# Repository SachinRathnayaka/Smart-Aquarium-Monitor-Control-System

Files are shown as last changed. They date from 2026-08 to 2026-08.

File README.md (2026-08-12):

<div align="center">

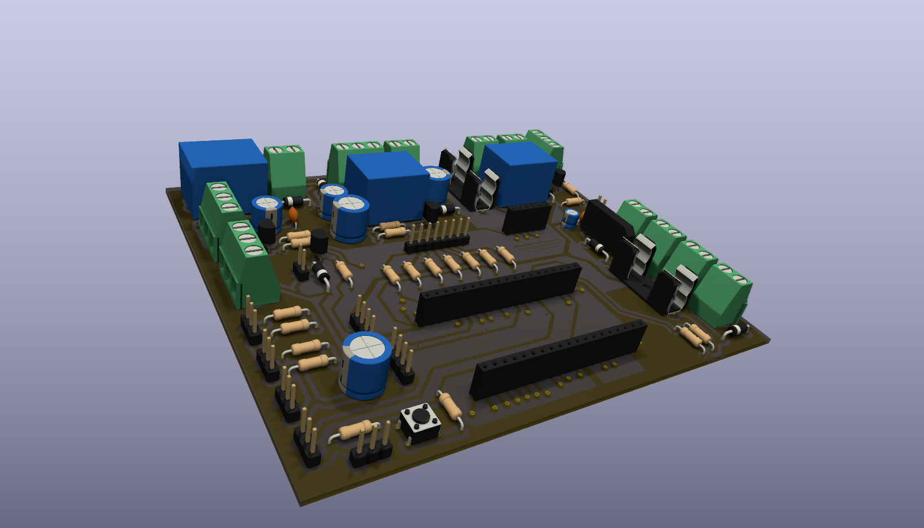
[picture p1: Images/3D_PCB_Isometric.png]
SRAqua Guard PCB


# 🐠 SRAqua Guard
### Ultimate Smart Aquarium Monitor & Automation System

*Real-time water telemetry · Intelligent automation · Voice control · Cross-platform monitoring*

---













**Author:** [Sachin Rathnayaka](https://github.com/SachinRathnayaka) &nbsp;·&nbsp; **Repo:** [Smart-Aquarium-Monitor-Control-System](https://github.com/SachinRathnayaka/Smart-Aquarium-Monitor-Control-System) &nbsp;·&nbsp; **Live Demo:** [Web Dashboard](https://sachinrathnayaka.github.io/Smart-Aquarium-Monitor-Control-System/)

</div>

---

## 📖 Table of Contents

- [Project Status](#-project-status)
- [Project Overview](#-project-overview)
- [Visual Showcase](#-visual-showcase)
- [Key Features](#-key-features)
- [System Architecture](#-system-architecture)
- [Repository Structure](#-repository-structure)
- [Getting Started](#-getting-started)
  - [Prerequisites](#prerequisites)
  - [1 · Firmware (ESP32)](#1--firmware-esp32)
  - [2 · Web Dashboard](#2--web-dashboard)
  - [3 · Android App](#3--android-app)
  - [4 · Windows Desktop App](#4--windows-desktop-app)
  - [Pre-built Binaries](#pre-built-binaries)
- [Firebase Configuration](#-firebase-configuration)
- [Voice Commands](#-voice-commands)
- [Sensor Calibration](#-sensor-calibration)
- [Troubleshooting](#-troubleshooting)
- [Electrical Safety](#-electrical-safety)
- [Hardware & PCB](#-hardware--pcb)
- [Bill of Materials](#-bill-of-materials-summary)
- [Roadmap](#️-roadmap)
- [Contributing](#-contributing)
- [Licensing](#-licensing)

---

## 🚧 Project Status

**Status: Active Development**

SRAqua Guard is an actively developed open-source hardware and software project. Features, firmware behaviour, PCB revisions, and application interfaces may change between releases. The project is functional and has been tested with real hardware — see the Visual Showcase for screenshots. Always refer to the latest `main` branch for the most current state.

| Component | Status |
|---|---|
| ESP32 Firmware | ✅ Functional |
| Web Dashboard | ✅ Functional |
| Android App | ✅ Functional |
| Windows Desktop App | ✅ Functional |
| KiCad PCB (Hardware) | ✅ Complete |
| Documentation | ✅ Complete |

---

## 🌊 Project Overview

**SRAqua Guard** is a fully open-source, advanced IoT aquarium monitoring and automation system that transforms any aquarium into an intelligently managed ecosystem. The system is built around an **ESP32 microcontroller** with a custom **KiCad PCB**, pushing real-time sensor telemetry to **Firebase Realtime Database**, and surfaced through three client platforms — a browser-based web dashboard, an Android mobile app, and a Windows desktop app.

The firmware is engineered with a **fully non-blocking `millis()` architecture**, a **DS3231 RTC** as the sole time source (ensuring offline-safe automation), and intelligent fallback behavior: the system continues sensing, controlling, and displaying locally even without Wi-Fi. When battery voltage drops below a threshold, the ESP32 enters a **5-minute deep sleep cycle** to preserve power.

> [!NOTE]
> This project includes **240 V AC mains wiring** for the water heater relay. All high-voltage sections must be handled by a qualified person. Use appropriate insulation, cable sleeving, and maintain required creepage clearances at all times.

---

## 🖼️ Visual Showcase

### Web Dashboard

| Overview | Firebase Setup | Theme Settings |
|:---:|:---:|:---:|
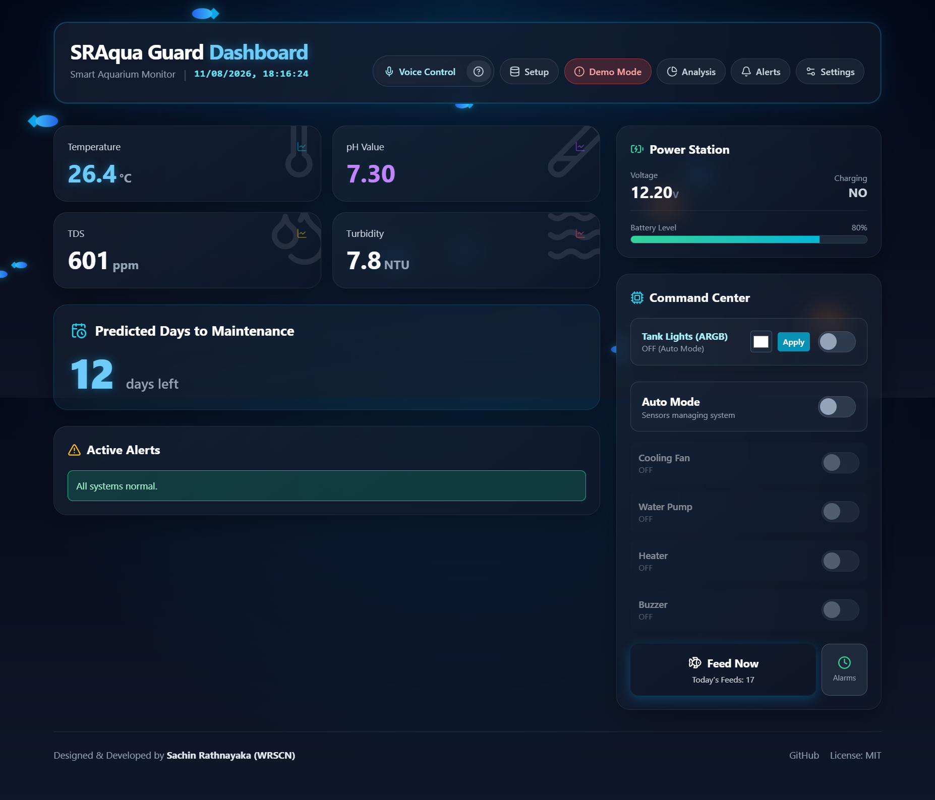
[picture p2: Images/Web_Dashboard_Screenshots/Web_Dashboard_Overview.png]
Overview
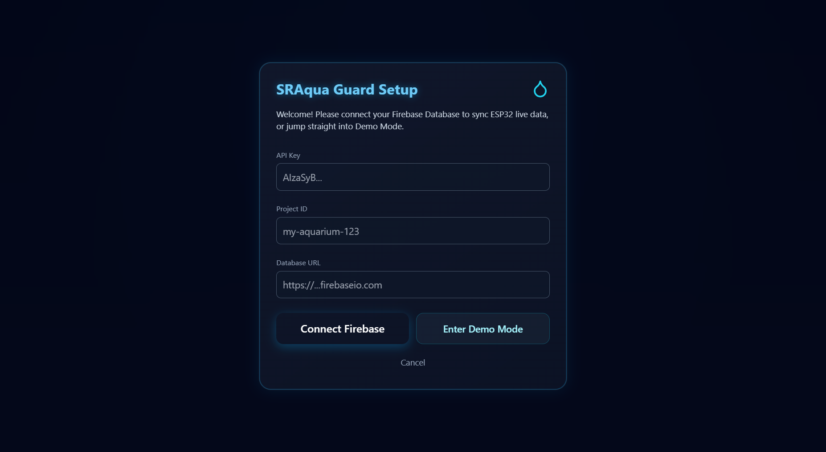
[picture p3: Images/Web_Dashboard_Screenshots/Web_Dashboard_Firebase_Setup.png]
Setup
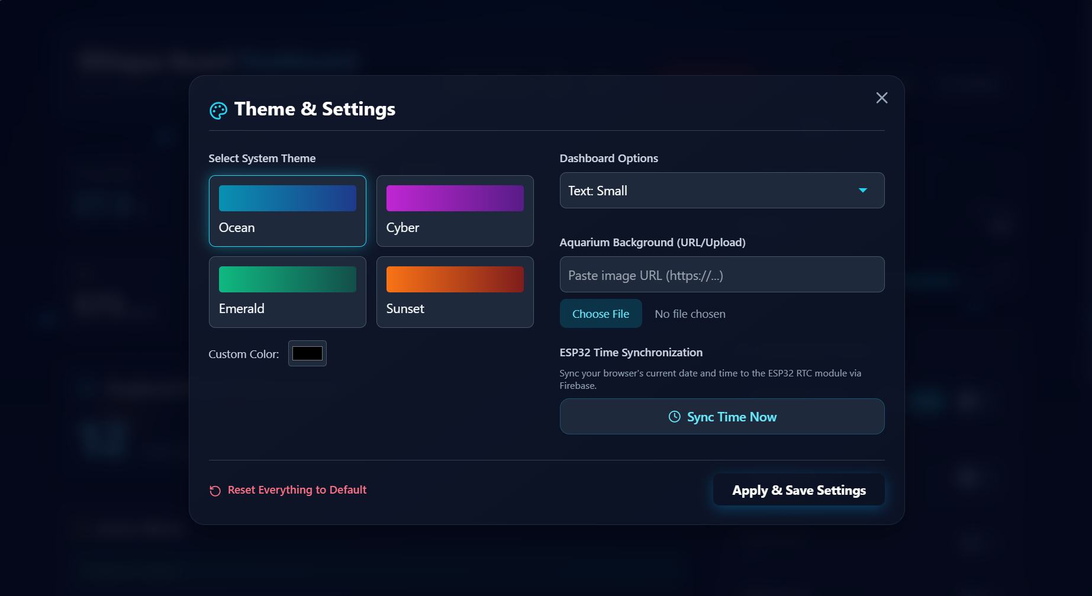
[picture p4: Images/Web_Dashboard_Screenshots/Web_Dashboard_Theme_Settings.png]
Themes
|  |  |  |

| 21-Day Sensor Analytics | 21-Day Feed Analytics | Auto Feeder Scheduler |
|:---:|:---:|:---:|
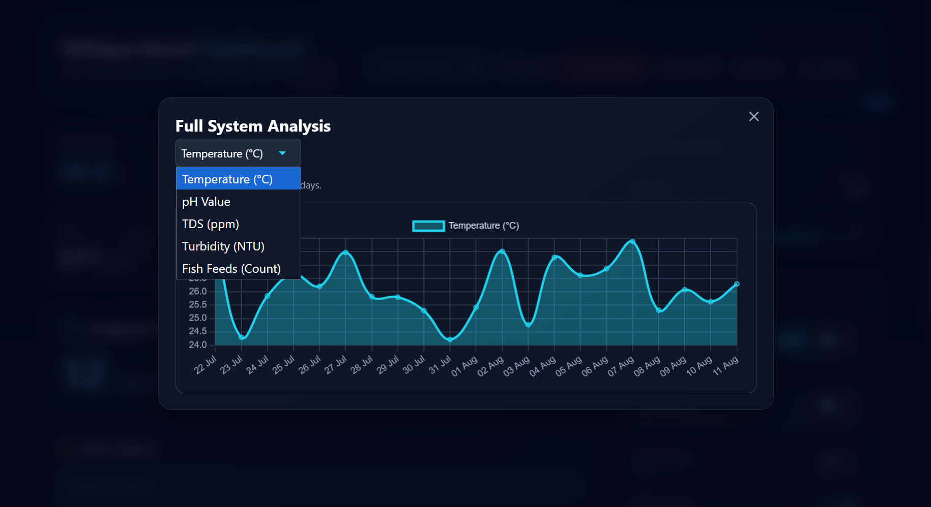
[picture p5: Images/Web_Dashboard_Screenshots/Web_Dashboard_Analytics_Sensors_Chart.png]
Sensor Chart
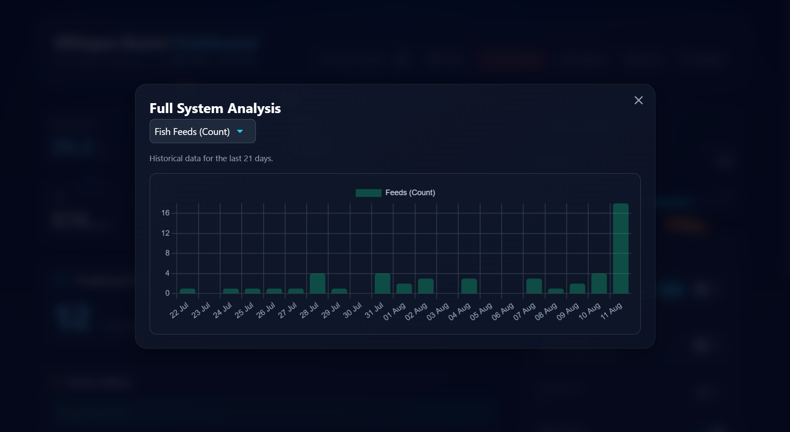
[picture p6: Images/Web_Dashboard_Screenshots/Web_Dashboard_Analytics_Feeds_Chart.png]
Feed Chart
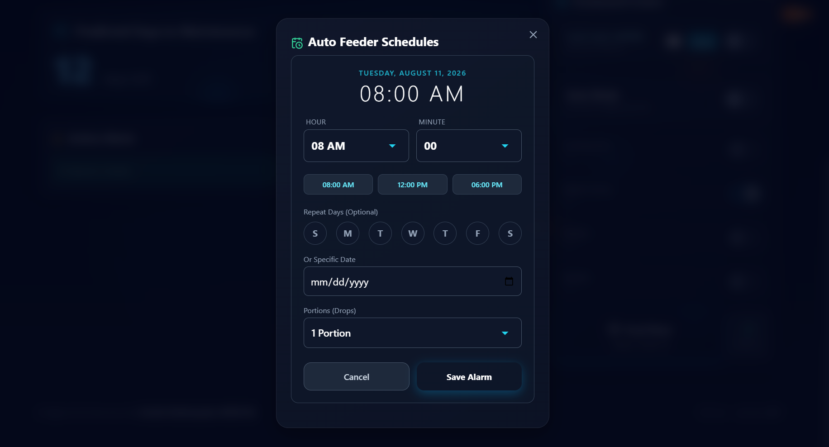
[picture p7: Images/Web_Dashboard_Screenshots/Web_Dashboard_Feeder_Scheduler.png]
Scheduler
|  |  |  |

| Live Voice Assistant | Voice Commands List | Alerts & History |
|:---:|:---:|:---:|
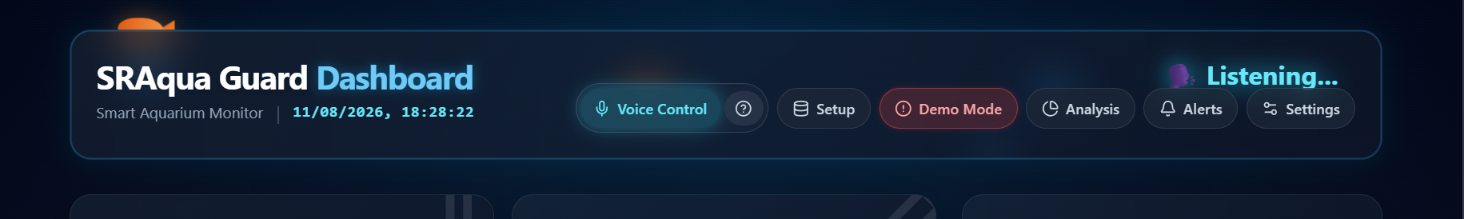
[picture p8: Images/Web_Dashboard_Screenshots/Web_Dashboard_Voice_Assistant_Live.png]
Voice Live
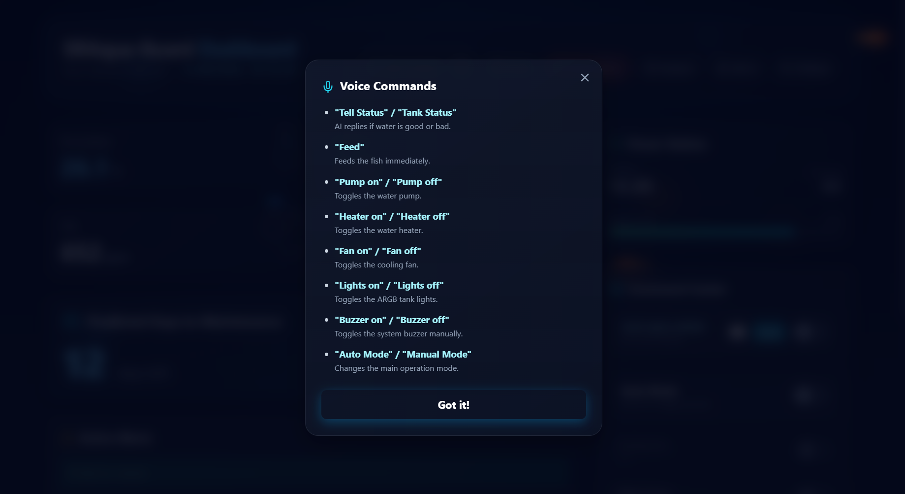
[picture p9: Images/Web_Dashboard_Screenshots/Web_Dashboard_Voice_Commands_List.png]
Voice Commands
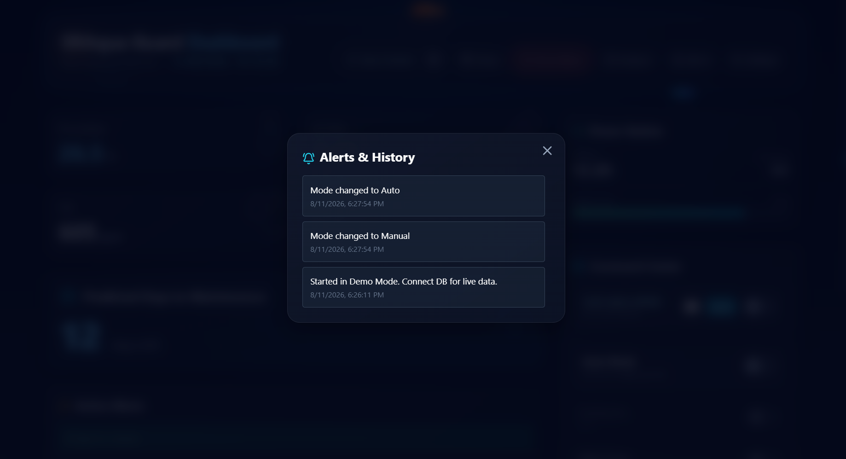
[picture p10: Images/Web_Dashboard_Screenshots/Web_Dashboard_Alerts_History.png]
Alerts
|  |  |  |

---

### Android Mobile App

| Firebase Setup | Telemetry & Sensors | Header Navigation | Command Center | App Icon |
|:---:|:---:|:---:|:---:|:---:|
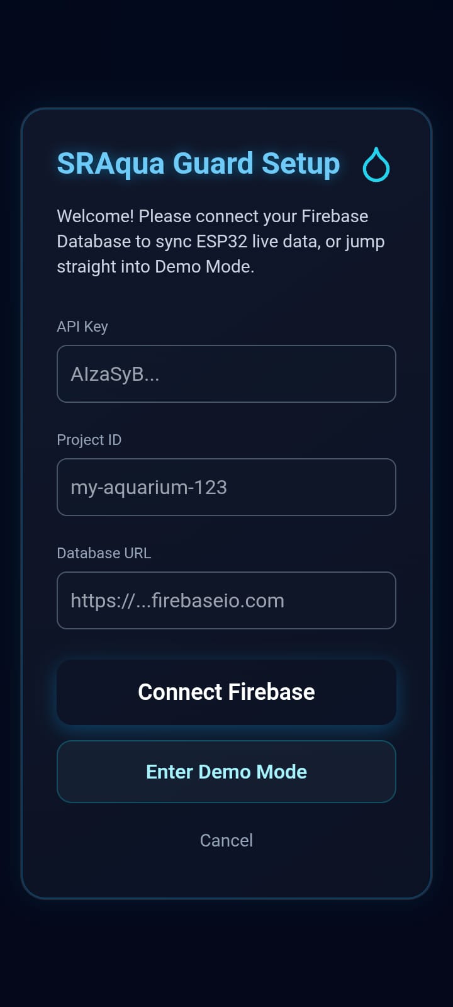
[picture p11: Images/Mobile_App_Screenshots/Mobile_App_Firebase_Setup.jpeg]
Setup
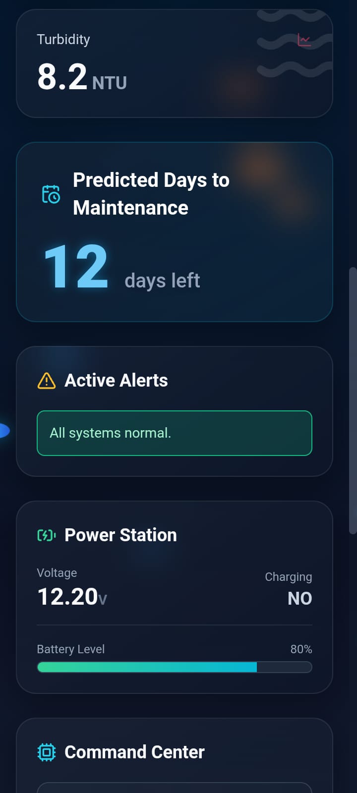
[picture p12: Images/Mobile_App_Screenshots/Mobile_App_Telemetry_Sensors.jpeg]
Sensors
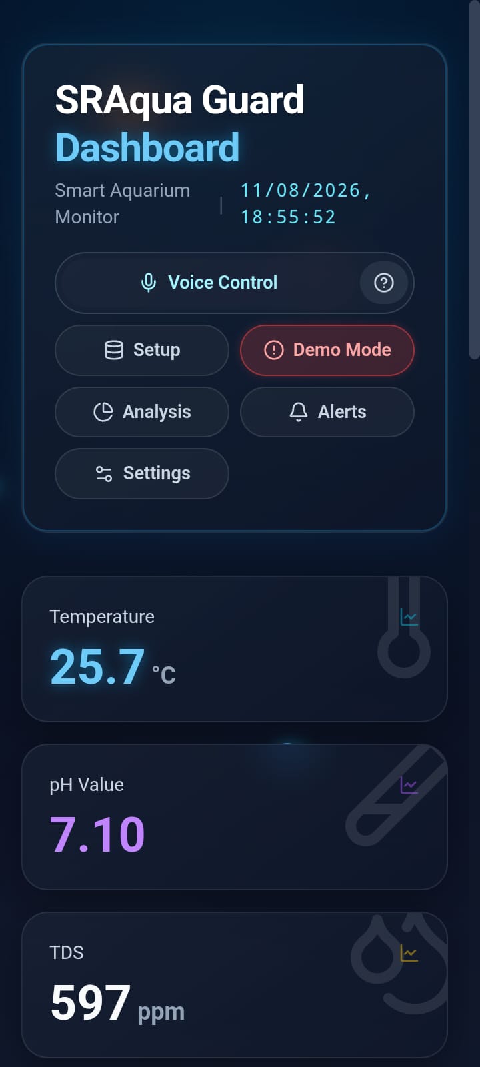
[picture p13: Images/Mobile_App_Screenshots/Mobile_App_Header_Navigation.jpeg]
Nav
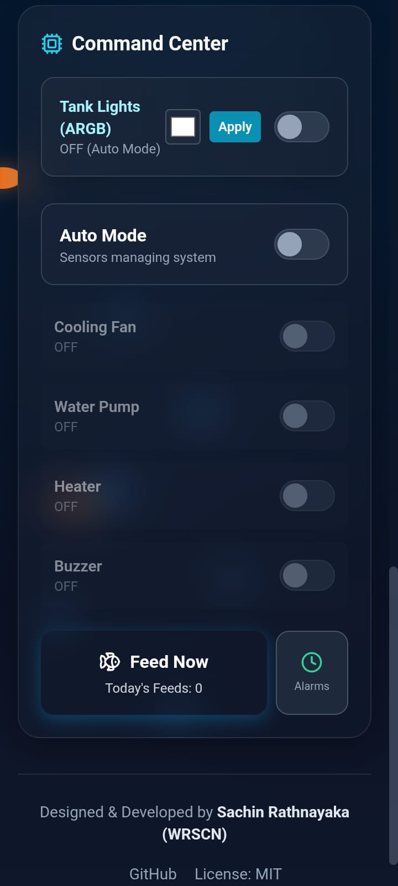
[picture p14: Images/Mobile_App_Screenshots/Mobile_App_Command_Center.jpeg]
Command
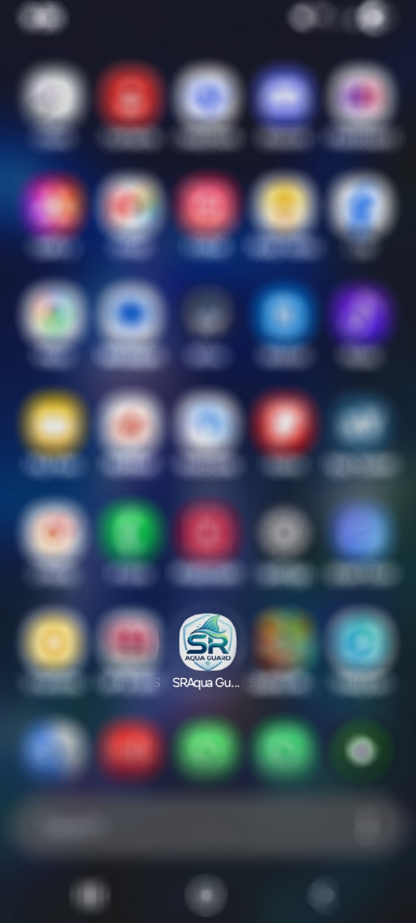
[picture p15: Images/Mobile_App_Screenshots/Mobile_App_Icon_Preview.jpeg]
Icon
|  |  |  |  |  |

---

### Windows Desktop App

| Main Dashboard | Firebase Setup | Theme Settings | Command Center | Desktop Icon |
|:---:|:---:|:---:|:---:|:---:|
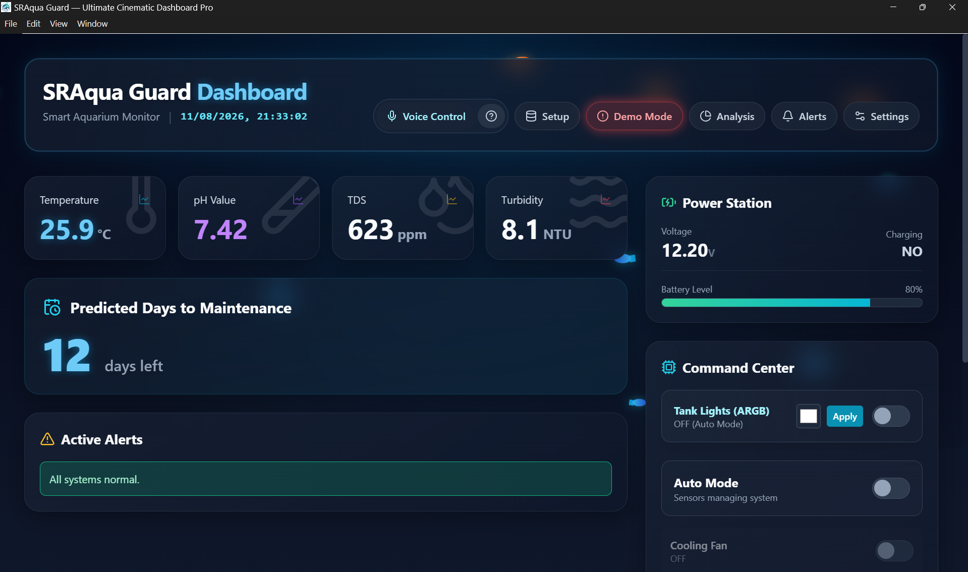
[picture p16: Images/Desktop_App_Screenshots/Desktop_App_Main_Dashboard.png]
Main
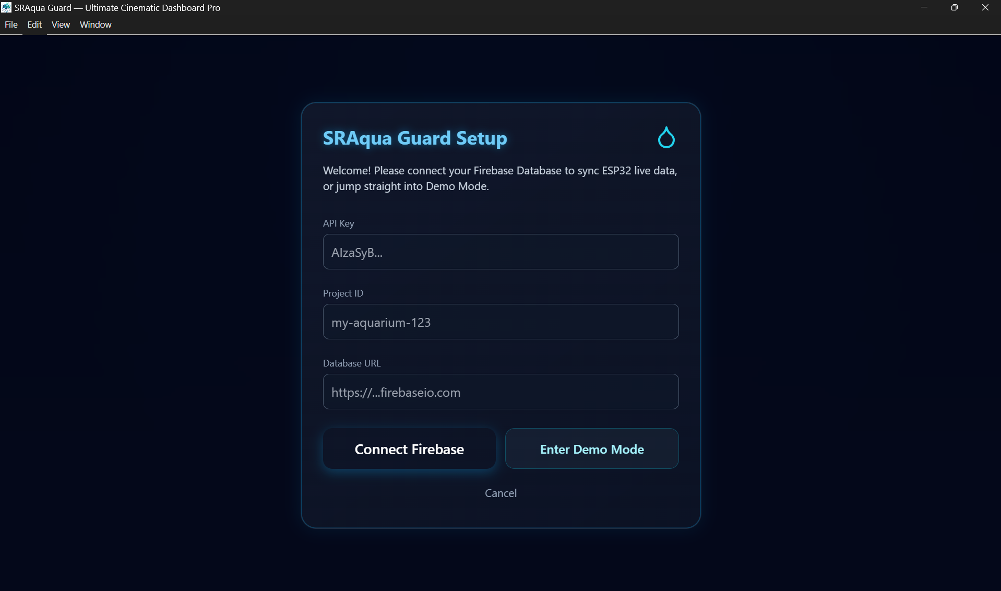
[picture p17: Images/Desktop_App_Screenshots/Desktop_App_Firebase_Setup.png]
Setup
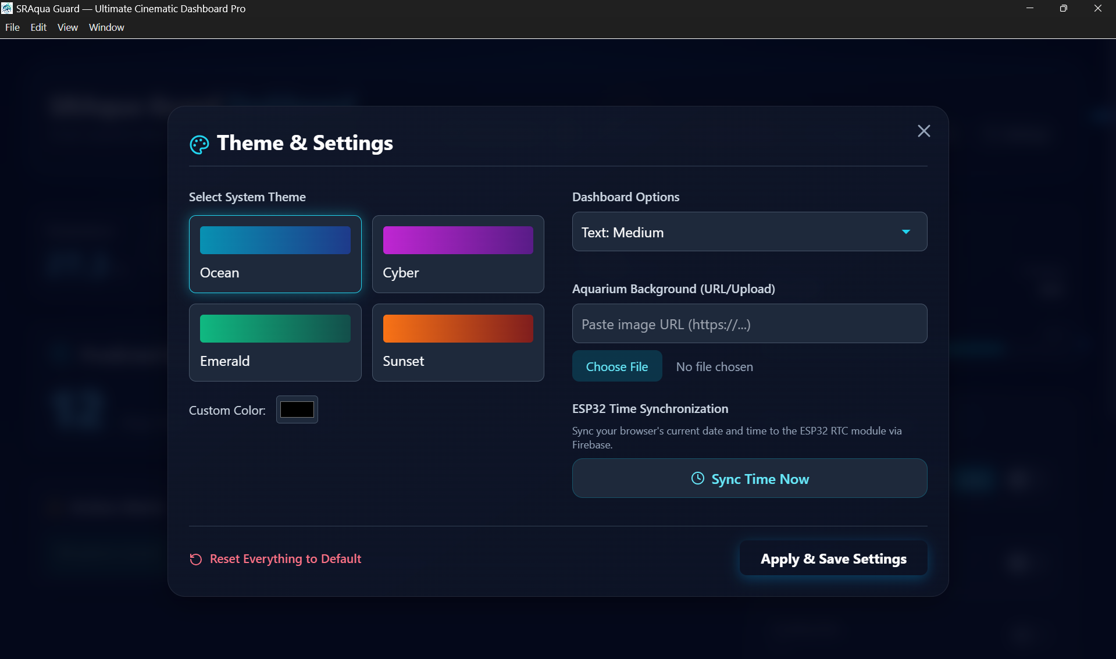
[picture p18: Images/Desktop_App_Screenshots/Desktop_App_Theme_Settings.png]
Theme
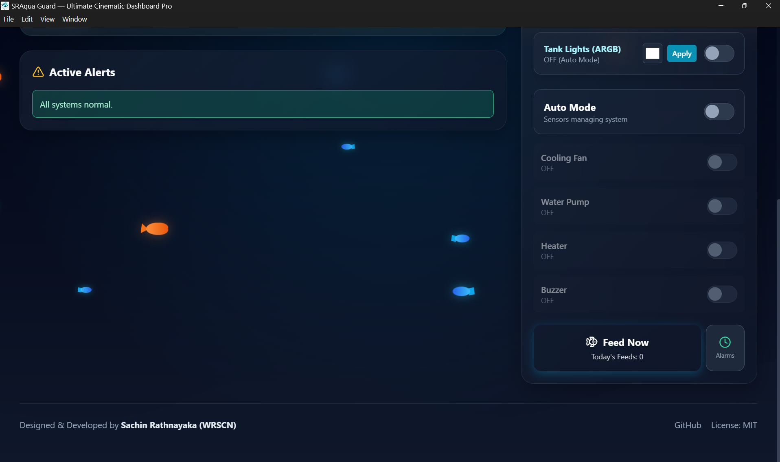
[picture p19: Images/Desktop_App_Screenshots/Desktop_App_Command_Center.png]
Command
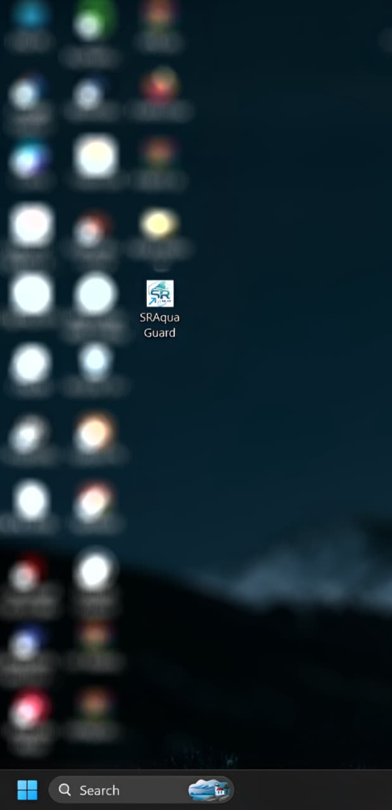
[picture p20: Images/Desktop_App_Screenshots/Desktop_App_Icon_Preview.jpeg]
Icon
|  |  |  |  |  |

---

### Custom KiCad PCB — 3D Renders

**Standard Renders**

| Top | Bottom | Front | Back | Left | Right |
|:---:|:---:|:---:|:---:|:---:|:---:|
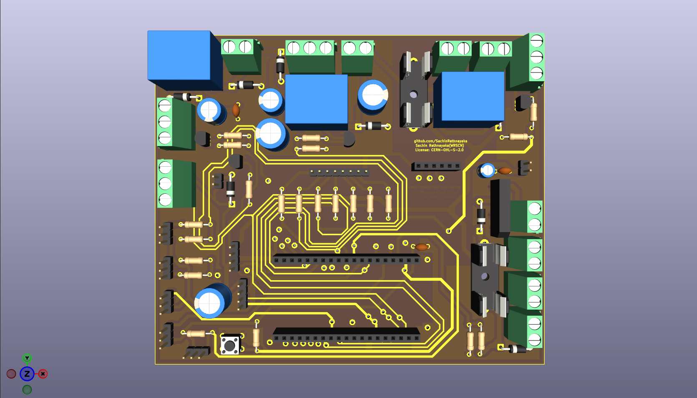
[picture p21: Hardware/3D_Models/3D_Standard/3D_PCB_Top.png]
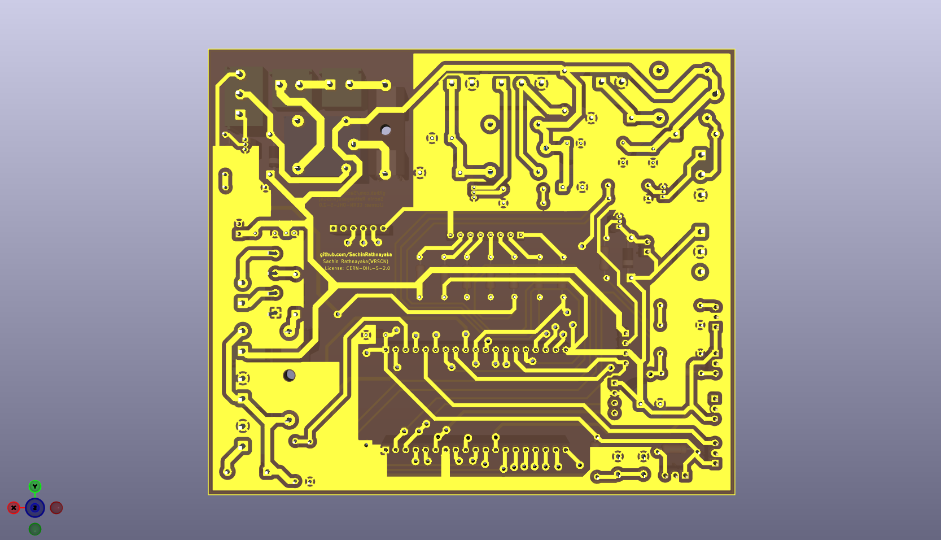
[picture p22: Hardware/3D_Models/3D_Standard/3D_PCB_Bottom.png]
Bottom
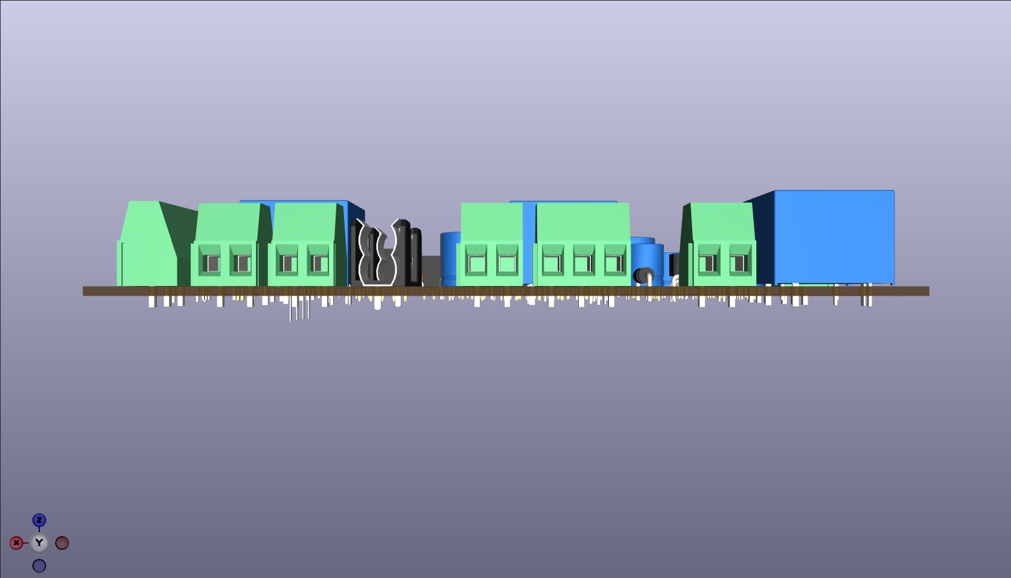
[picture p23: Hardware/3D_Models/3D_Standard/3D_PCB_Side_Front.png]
Front
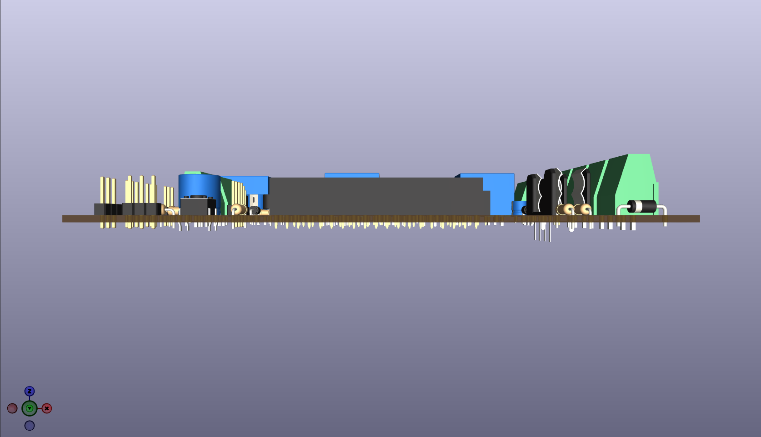
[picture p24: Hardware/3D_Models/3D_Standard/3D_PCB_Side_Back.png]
Back
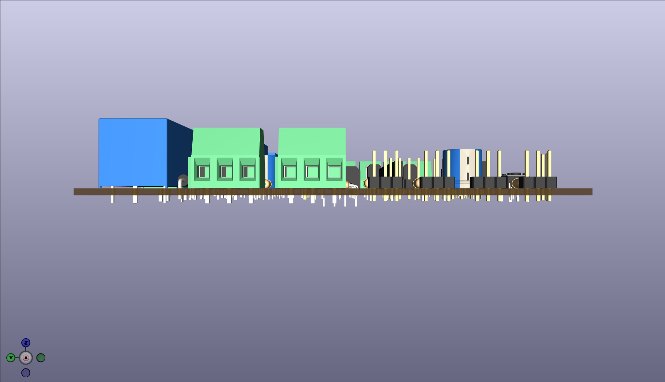
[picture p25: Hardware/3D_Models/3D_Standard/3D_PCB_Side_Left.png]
Left
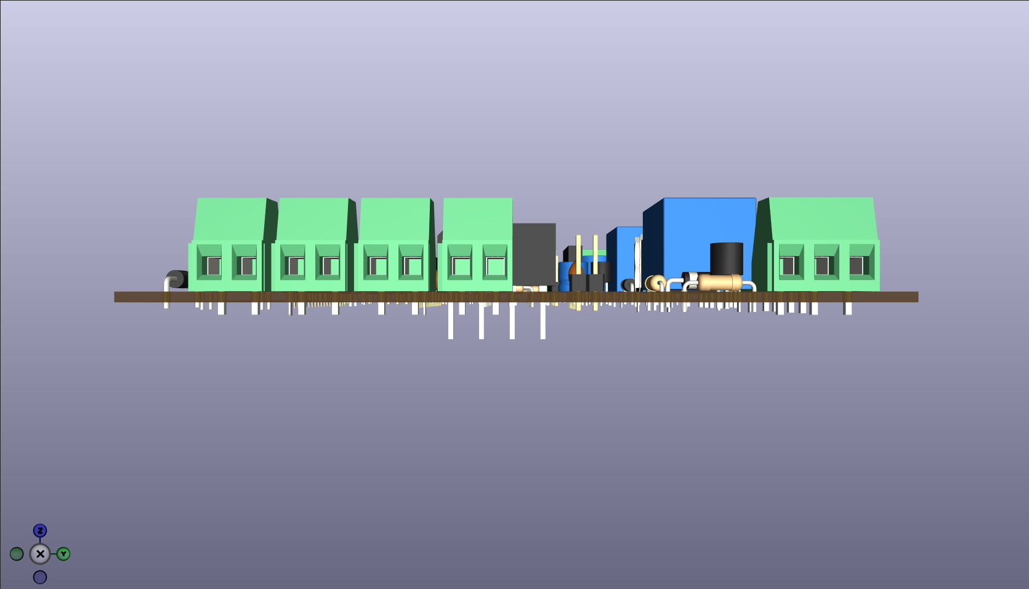
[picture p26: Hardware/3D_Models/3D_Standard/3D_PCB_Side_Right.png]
Right
|  |  |  |  |  |  |

**Raytraced Renders**

| Top | Bottom | Front | Back | Left | Right |
|:---:|:---:|:---:|:---:|:---:|:---:|
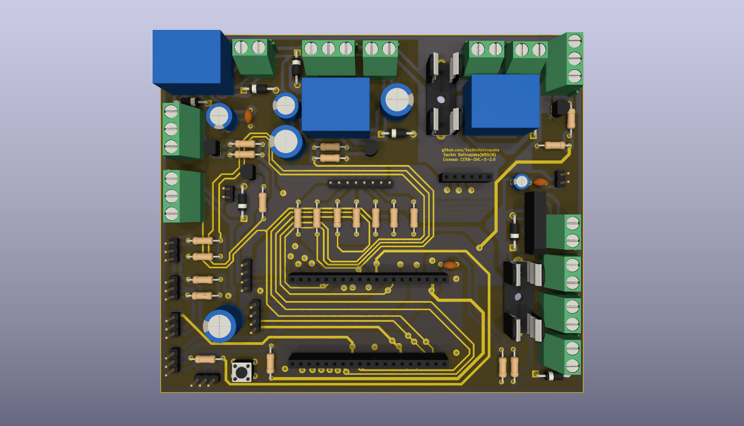
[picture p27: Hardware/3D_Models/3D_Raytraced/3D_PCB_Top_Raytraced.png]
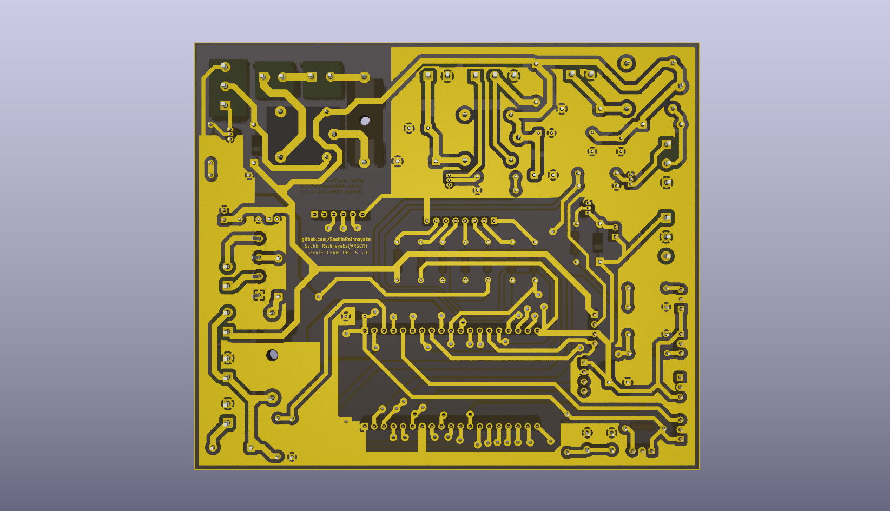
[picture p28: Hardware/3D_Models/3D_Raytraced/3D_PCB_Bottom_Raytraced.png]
Bottom
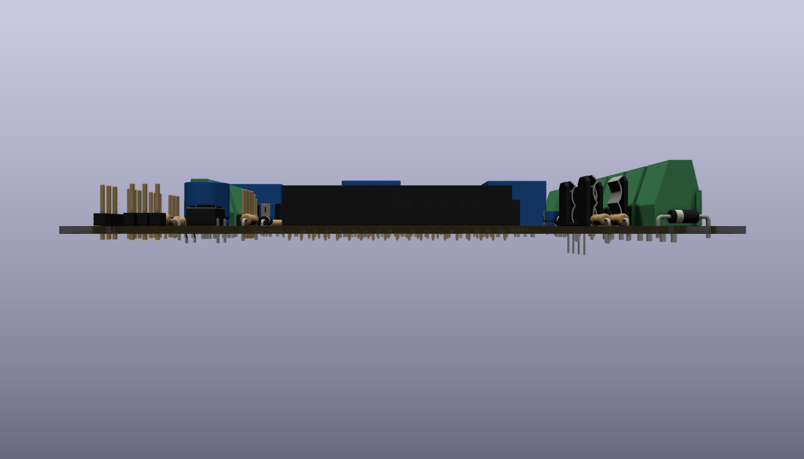
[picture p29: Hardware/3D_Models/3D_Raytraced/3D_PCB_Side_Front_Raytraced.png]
Front
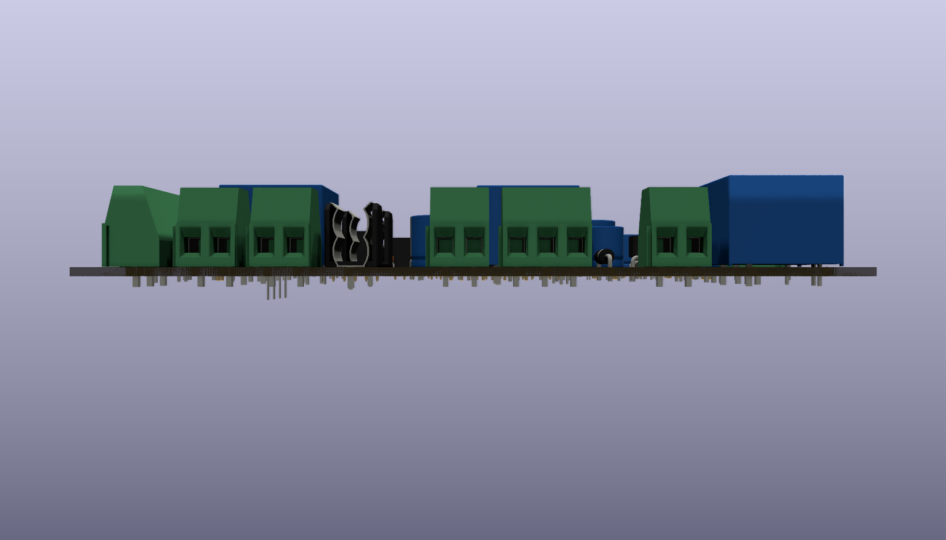
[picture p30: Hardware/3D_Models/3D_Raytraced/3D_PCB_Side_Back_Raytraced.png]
Back
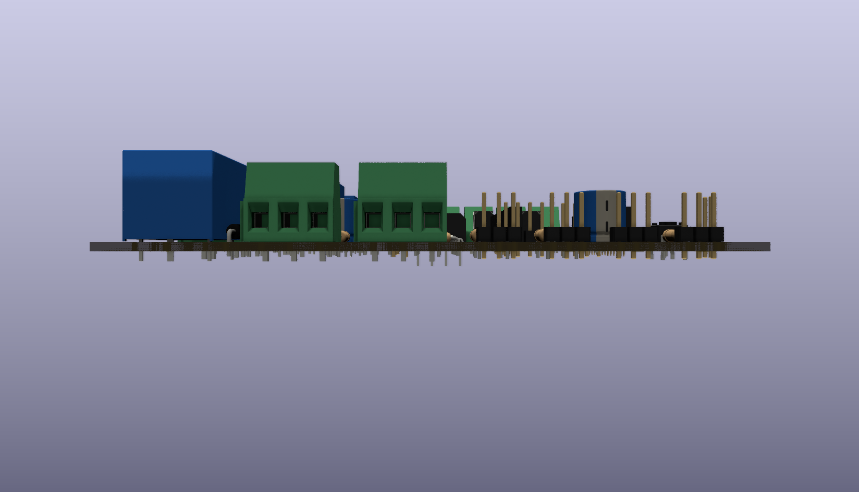
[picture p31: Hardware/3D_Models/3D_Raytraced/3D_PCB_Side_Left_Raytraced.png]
Left
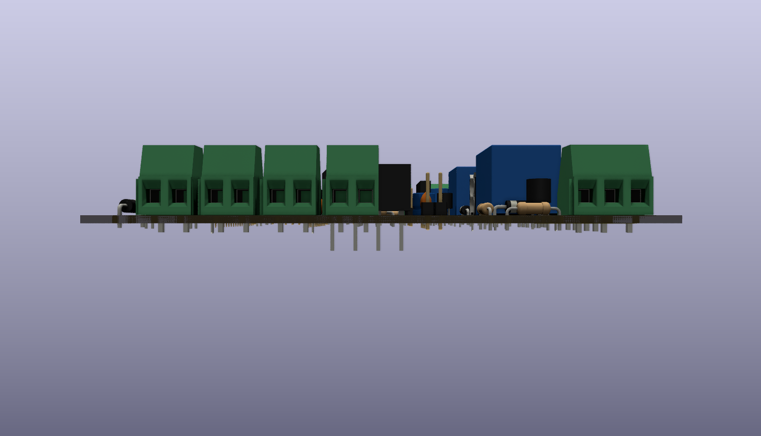
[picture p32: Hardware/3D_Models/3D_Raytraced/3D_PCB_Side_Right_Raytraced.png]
Right
|  |  |  |  |  |  |

---

## ✨ Key Features

### 🔬 Water Quality Telemetry
- **Temperature** via DS18B20 OneWire sensor — with DS18B20 power-on sentinel (85 °C) rejection
- **pH** via analog sensor module — linear calibration with configurable slope/offset
- **TDS (Total Dissolved Solids)** via analog sensor — temperature-compensated formula
- **Turbidity** via analog sensor — quadratic NTU conversion with 20-point Simple Moving Average (SMA) and degradation trend prediction (days to next maintenance)
- Sensor readings every **2 seconds** in non-blocking loop

### ⚙️ Intelligent Automation
| Condition | Automatic Response |
|---|---|
| Temperature > 29 °C | Cooling fan ON |
| Temperature < 25 °C | Water heater ON (with 30-min hard safety cutoff) |
| Turbidity > 35 NTU or TDS > 500 ppm | Submersible pump ON |
| Turbidity > 70 NTU | Alarm buzzer ON |
| pH outside 6.3–8.3 | Alarm buzzer ON |
| TDS > 1200 ppm | Auto water-change sequence (8-min max, 1-hr cooldown) |
| Pump running 2 h+ with high turbidity | Filter-change alert pushed to Firebase + LCD |
| Temperature sensor fault (OOR / 85 °C sentinel) | Heater hard-disabled, buzzer triggered |
| Battery-only inferred (voltage < 11.2 V, no charge trend) | All loads OFF → 5-min deep sleep cycle |

### 💡 ARGB Lighting Day-Cycle (RTC-driven)
| Time | Lighting |
|---|---|
| 06:00 – 09:59 | Sunrise — dim orange / warm yellow |
| 10:00 – 17:59 | Daytime — bright white / light blue |
| 18:00 – 05:59 | Night — calm breathing blue/purple (non-blocking animation) |

### 🎙️ Voice Assistant
- **8 core command groups** (Status · Feed · Pump · Heater · Fan · Lights · Buzzer · Mode) plus Demo Mode test commands, via the **Web Speech API** — no cloud API key required
- Live transcription displayed in the dashboard header (auto-stops after 15 s of silence, or 5 s after the last detected word)
- Voice TTS feedback: browser speaks alert summaries aloud

### 📅 Auto Fish Feeder
- Servo-based feeder FSM (4-state: Idle → Extend → Hold → Return)
- Unlimited scheduled feeds — configurable time, day(s) of week, specific date, and portion count
- Manual one-click feed button on web/local dashboard
- Daily feed counter persisted in browser `localStorage`

### 🔋 Power Telemetry
- 12 V battery voltage via resistor-divider (×4 ratio) on GPIO 33
- Battery percentage from 9.0 V (0%) to 12.6 V (100%)
- Charging inference via 10-point voltage trend (>50 mV rise = charging)
- Solar charging input terminal on PCB (J15)

### 🖥️ Web Dashboard

👉 **[🚀 Try Live Web Dashboard Here](https://sachinrathnayaka.github.io/Smart-Aquarium-Monitor-Control-System/)** *(Fully functional Demo Mode available — no hardware required!)*

- Pure single-file HTML5/CSS3/JavaScript — **zero build step, zero dependencies to install**
- Firebase Realtime Database v10.8.0 SDK — real-time bidirectional sync
- **4 built-in themes:** Ocean · Cyber · Emerald · Sunset + custom hex color picker
- **Demo Mode** — fully functional without any hardware (simulated sensor data)
- 21-day historical analytics charts (Temperature, pH, TDS, Turbidity, Feed count) via Chart.js
- ARGB hex color picker — picks and syncs live `light_color` to Firebase
- RTC time sync — pushes browser clock to ESP32 via Firebase (`/commands/rtc_sync`)
- Alerts & notification history (last 50 events)

---

## 🏗️ System Architecture

```
┌─────────────────────────────────────────────────────────────────────┐
│                        ESP32 (Firmware)                             │
│                                                                     │
│  Sensors ──► readAllSensors() ──► evaluateAutomation()              │
│  DS18B20 · pH · TDS · Turbidity · Battery                           │
│                    │                                                │
│         millis() non-blocking loop (no delay())                     │
│                    │                                                │
│  ┌─────────────────┼─────────────────────────┐                     │
│  │ DS3231 RTC      │ FastLED ARGB   Servo     │                     │
│  │ (offline time)  │ (day cycle)    (feeder)  │                     │
│  └─────────────────┼─────────────────────────┘                     │
│                    │                                                │
│         pushFirebase() every 5 s  ◄──►  Firebase RTDB              │
│         streamCallback()          ◄──►  /controls + /commands       │
│         Local WebServer (port 80) → in-network dashboard            │
└─────────────────────────────────────────────────────────────────────┘
                              │
                  Firebase Realtime Database
                  /devices/aquaSense/
                  ├── sensors/
                  ├── status/
                  ├── controls/
                  ├── commands/
                  └── alerts/
                              │
          ┌───────────────────┼───────────────────┐
          │                   │                   │
   Web Dashboard        Android App         Windows App
   (index.html)     (WebView wrapper)    (Electron shell)
   Any browser      com.wrscn.sraquaguard  com.wrscn.sraquaguard
```

### ESP32 GPIO Pin Map

| Pin | Signal | Direction |
|-----|---|---|
| GPIO 34 | pH Sensor (Analog) | Input |
| GPIO 35 | TDS Sensor (Analog) | Input |
| GPIO 32 | Turbidity Sensor (Analog) | Input |
| GPIO 25 | DS18B20 Temperature (1-Wire) | Input |
| GPIO 33 | BMS / Battery Voltage (Analog) | Input |
| GPIO 26 | Cooling Fan Relay | Output |
| GPIO 27 | Submersible Pump Relay | Output |
| GPIO 17 | Water Heater Relay ⚠️ 240 V | Output |
| GPIO 23 | Fish Feeder Servo (PWM) | Output |
| GPIO 16 | ARGB LED Strip (WS2812B) | Output |
| GPIO 13 | Alarm Buzzer | Output |
| GPIO 21 | I²C SDA (LCD + RTC) | I²C |
| GPIO 22 | I²C SCL (LCD + RTC) | I²C |
| GPIO 4 | Wi-Fi / Firebase Status LED | Output |

### Arduino Libraries Required

| Library | Purpose | Install via |
|---|---|---|
| `Firebase ESP Client` by mobizt | Firebase RTDB | Arduino Library Manager |
| `LiquidCrystal I2C` | 16×2 LCD display | Arduino Library Manager |
| `DallasTemperature` | DS18B20 sensor | Arduino Library Manager |
| `OneWire` | 1-Wire bus | Arduino Library Manager |
| `RTClib` | DS3231 RTC | Arduino Library Manager |
| `FastLED` | WS2812B ARGB LEDs | Arduino Library Manager |
| `ESP32Servo` | Servo motor control | Arduino Library Manager |

---

## 📁 Repository Structure

```
Smart-Aquarium-Monitor-Control-System/
│
├── 📁 Firmware/
│   └── ESP32/
│       └── IoT_Based_Smart_Aquarium_Monitor__Control_System_ESP32/
│           ├── IoT_Based_Smart_Aquarium_Monitor__Control_System_ESP32.ino
│           │   # Main ESP32 firmware — non-blocking millis() architecture,
│           │   # offline-safe automation, DS3231 RTC, Firebase RTDB streaming,
│           │   # ARGB day cycle, feeder FSM, battery telemetry, deep sleep
│           └── secrets.example.h
│               # Credential template — copy to secrets.h, fill in values,
│               # add secrets.h to .gitignore (never commit real credentials)
│
├── 📁 Web_Dashboard/
│   ├── index.html          # Single-file dashboard — no build step required
│   └── assets/
│       └── logo.png
│
├── 📁 Android_App/          # Android Studio project (com.wrscn.sraquaguard)
│   ├── app/
│   │   ├── build.gradle    # compileSdk 35, minSdk 23 (Android 6.0+), versionName 1.0
│   │   └── src/main/
│   │       ├── AndroidManifest.xml
│   │       ├── assets/
│   │       │   ├── index.html      # Bundled web dashboard
│   │       │   └── assets/logo.png
│   │       ├── java/com/wrscn/sraquaguard/
│   │       │   └── MainActivity.java  # WebView with immersive fullscreen
│   │       └── res/
│   │           ├── drawable/sraqua_logo.png
│   │           ├── mipmap-*/       # Launcher icons (all densities)
│   │           └── values/
│   │               ├── colors.xml
│   │               └── styles.xml  # Theme.SRAquaGuard (dark slate)
│   └── README.md
│
├── 📁 Windows_App/          # Electron desktop application
│   ├── main.js             # BrowserWindow 1280×800, contextIsolation: true
│   ├── index.html          # Dashboard file loaded by Electron
│   ├── package.json        # electron + electron-builder, NSIS target
│   ├── package-lock.json
│   └── assets/
│       ├── logo.ico        # Windows app icon
│       └── logo.png
│
├── 📁 Hardware/             # KiCad 10.0.3 PCB project
│   ├── *.kicad_pcb         # PCB layout
│   ├── *.kicad_sch         # Schematic
│   ├── *.kicad_pro         # Project file
│   ├── 3D_Models/
│   │   ├── 3D_Standard/    # 6 standard 3D renders (Top/Bottom/Sides)
│   │   └── 3D_Raytraced/   # 6 raytraced 3D renders (Top/Bottom/Sides)
│   ├── Gerber_Files/       # Full Gerber set (F_Cu, B_Cu, Masks, Silkscreen,
│   │   ├── *.gbr           #   Edge Cuts, Drill files) + zipped Gerber bundle
│   │   └── Gerber_ZIP/
│   └── DIY_Etching_PDFs/   # PDFs for DIY toner-transfer / UV etching
│       ├── Copper_Layers/  # Top + Bottom copper (normal + mirrored)
│       ├── Silkscreen_Layers/
│       └── Assembly_Drawings/
│
├── 📁 Docs/
│   ├── Bill_of_Materials.md          # 41 line items · 74 total components
│   ├── Components_List_BOM.csv       # Machine-readable BOM
│   ├── Schematic_Diagram.pdf         # Full schematic PDF export
│   └── PCB_Artwork_Etching_Layout.pdf
│
├── 📁 Images/               # All screenshots and renders used in this README
│   ├── 3D_PCB_Isometric.png
│   ├── ESP32_Pin_Pitch_Dimensions.png
│   ├── Web_Dashboard_Screenshots/    # 9 screenshots
│   ├── Mobile_App_Screenshots/       # 5 screenshots
│   └── Desktop_App_Screenshots/      # 5 screenshots
│
└── README.md
```

---

## 🚀 Getting Started

### Prerequisites

| Requirement | Details |
|---|---|
| Arduino IDE ≥ 2.x **or** PlatformIO | For flashing the ESP32 firmware |
| ESP32 Arduino Core | Board package for ESP32 (add `https://raw.githubusercontent.com/espressif/arduino-esp32/gh-pages/package_esp32_index.json` to board manager) |
| Firebase project | Free Spark plan is sufficient — Realtime Database enabled |
| Any modern browser | Chrome recommended for Voice Control (Web Speech API) |
| Android Studio (optional) | To build the `.apk` from source |
| Node.js ≥ 18 (optional) | To run/build the Windows Electron app from source |

---

### 1 · Firmware (ESP32)

#### Step 1 — Install Libraries

Open **Arduino IDE → Tools → Manage Libraries** and install each of the following:

```
Firebase ESP Client    (by mobizt)
LiquidCrystal I2C
DallasTemperature
OneWire
RTClib
FastLED
ESP32Servo
```

#### Step 2 — Configure Credentials (secrets.h pattern)

To avoid accidentally committing credentials to a public repository, use the recommended `secrets.h` approach:

**2a.** Copy the provided template:
```
Firmware/ESP32/.../secrets.example.h  →  copy as  secrets.h
```

**2b.** Open `secrets.h` and fill in your values:
```cpp
// secrets.h — DO NOT commit this file
#pragma once

// Wi-Fi
#define WIFI_SSID     "YOUR_WIFI_SSID"
#define WIFI_PASSWORD "YOUR_WIFI_PASSWORD"

// Firebase
#define API_KEY       "YOUR_FIREBASE_API_KEY"
#define DATABASE_URL  "YOUR_FIREBASE_DATABASE_URL"
#define USER_EMAIL    "YOUR_FIREBASE_USER_EMAIL"
#define USER_PASSWORD "YOUR_FIREBASE_USER_PASSWORD"
```

**2c.** Add `secrets.h` to your `.gitignore` so it is never tracked:
```
# .gitignore
secrets.h
```

The main `.ino` file already contains `#include "secrets.h"` and uses these defines — **do not paste real credentials directly into the `.ino` file.**

> [!WARNING]
> **Never commit real credentials to a public repository.** The `secrets.example.h` template uses intentionally non-functional placeholder strings. Always work from `secrets.h` (git-ignored) in your local copy.

> [!NOTE]
> **Firebase API Key vs secret credentials:** The Firebase Web API Key (found in Project Settings) is a *project identifier* — it is not a secret by itself, as it is embedded in every web client. What must be protected are your **Firebase Auth user email and password** (the device account). Firebase Database Rules (see the Firebase Configuration section) are your primary security boundary — ensure they are correctly configured before going live.

#### Step 3 — Sensor Calibration (optional)

The firmware ships with **Dummy Data switches** that generate realistic random values for dry testing without any sensors connected:

```cpp
bool DUMMY_PH        = false;   // set true for dry test
bool DUMMY_TDS       = false;
bool DUMMY_TURBIDITY = false;
bool DUMMY_TEMP      = false;
bool DUMMY_BATTERY   = false;
```

For a real deployment, calibrate your pH probe and update:

```cpp
float PH_SLOPE  = -5.70f;   // Adjust after 2-point calibration
float PH_OFFSET = 21.34f;
```

#### Step 4 — Flash

Select **Board: `ESP32 Dev Module`**, choose the correct COM port, then click **Upload**.

---

### 2 · Web Dashboard

The dashboard is a **single self-contained HTML file** with no build step.

**Option A — Open locally in browser**
```
Open Web_Dashboard/index.html directly in Chrome or Edge
```

**Option B — Host on GitHub Pages**
1. Copy `Web_Dashboard/index.html` and `Web_Dashboard/assets/` to the root of a GitHub Pages branch.
2. Enable GitHub Pages in your repository settings.
3. Share the `https://<username>.github.io/<repo>/` URL.

**Connecting to Firebase**

When the dashboard loads, a setup modal appears. Enter your Firebase project credentials:

| Field | Where to find it |
|---|---|
| **API Key** | Firebase Console → Project Settings → General |
| **Database URL** | Firebase Console → Realtime Database → Data tab |
| **User Email** | Firebase Console → Authentication → Users |
| **User Password** | The password for that Firebase Auth user |

Click **Connect Firebase** to go live, or **Enter Demo Mode** to explore with simulated data — no hardware needed.

---

### 3 · Android App

**Build from source (Android Studio)**

1. Open the `Android_App/` folder in **Android Studio**.
2. Allow Gradle to sync (compileSdk 35, minSdk 23 — Android 6.0+).
3. Build the APK:

```bash
./gradlew assembleDebug
# Output: Android_App/app/build/outputs/apk/debug/app-debug.apk
```

Or use **Build → Build App Bundle(s)/APK(s) → Build APK(s)** from the menu.

The app loads `index.html` bundled in `app/src/main/assets/` via a hardware-accelerated WebView with immersive fullscreen mode. Firebase credentials are configured through the in-app setup modal — no separate `google-services.json` is needed.

> [!NOTE]
> The web dashboard inside the APK includes its own Firebase setup flow. Simply enter your Firebase credentials the first time you launch the app, and they are persisted in the WebView's `localStorage`.

---

### 4 · Windows Desktop App

**Run from source**

```bash
cd Windows_App
npm install
npm start
```

**Build an installable `.exe`**

```bash
npm run build
# Output: Windows_App/dist/SRAqua Guard Setup x.x.x.exe  (NSIS installer)
```

The Electron window opens at **1280 × 800** (minimum 1000 × 650) and loads `index.html`. Node integration is disabled (`nodeIntegration: false`, `contextIsolation: true`) for security.

---

### Pre-built Binaries

Pre-compiled binaries are published through the **GitHub Releases** page. Check the Releases tab for the latest available versions:

| Platform | File | Notes |
|---|---|---|
| Android | `SRAqua_Guard_v1.0.apk` | Sideload — enable "Install from unknown sources" in device settings |
| Windows | `SRAqua Guard Setup 1.0.0.exe` | NSIS installer — run and follow on-screen prompts |

👉 **[View GitHub Releases](https://github.com/SachinRathnayaka/Smart-Aquarium-Monitor-Control-System/releases)**

> [!NOTE]
> If no release is listed yet, build from source using the instructions above — it only takes a few minutes.

---

## 🔥 Firebase Configuration

### Database Path Structure

All device data lives under a single root path:

```
/devices/aquaSense/
├── sensors/            ← pushed by ESP32 every 5 s
│   ├── temperature_c
│   ├── ph_value / ph_voltage
│   ├── tds_ppm / tds_voltage
│   ├── turbidity_ntu / turbidity_sma
│   ├── predicted_days_to_maintenance
│   ├── battery_voltage / battery_percent
│   ├── charging_inferred
│   ├── dummy_ph / dummy_tds / dummy_turbidity / dummy_temp / dummy_battery
│   └── timestamp
├── status/             ← pushed by ESP32 every 5 s
│   ├── manual_mode / fan / pump / heater / buzzer
│   ├── water_change_active / filter_change_required
│   ├── wifi_connected / firebase_ready / battery_only_mode
├── controls/           ← written by dashboard, read by ESP32 stream
│   ├── manual_mode / manual_fan / manual_pump
│   ├── manual_heater / manual_buzzer
│   ├── manual_light / light_color
│   └── feed_now
├── commands/           ← one-shot voice hooks (auto-reset after each push)
│   ├── voice_feed
│   ├── voice_pump
│   └── rtc_sync
└── alerts/
    └── filter_change_required_at
```

### Recommended Security Rules

The rules below apply **least-privilege** access: only authenticated users can read or write device data. No unauthenticated access is permitted at any path.

```json
{
  "rules": {
    ".read":  false,
    ".write": false,
    "devices": {
      "aquaSense": {
        "sensors":  { ".read": "auth != null", ".write": "auth != null" },
        "status":   { ".read": "auth != null", ".write": "auth != null" },
        "controls": { ".read": "auth != null", ".write": "auth != null" },
        "commands": { ".read": "auth != null", ".write": "auth != null" },
        "alerts":   { ".read": "auth != null", ".write": "auth != null" }
      }
    }
  }
}
```

> [!IMPORTANT]
> **Never use `".read": true, ".write": true`** (open rules) — this exposes your device data to anyone on the internet. The root-level `false` defaults above ensure that any path not explicitly listed is denied by default. The firmware authenticates using the dedicated Firebase Auth device account configured in `secrets.h`.

> [!NOTE]
> For a single-owner deployment, the `auth != null` check is sufficient since only your device account and your own dashboard sessions are authenticated. For multi-user or team setups, consider tightening rules further using `auth.uid` matching against an allow-list stored in the database.

> [!TIP]
> **Future enhancement — role-based rules:** In an ideal setup, write permissions would be further restricted by path role: `sensors/` and `status/` would be write-restricted to the ESP32 device account only, while `controls/` and `commands/` would be writable by dashboard users. This can be implemented by storing your ESP32's Firebase Auth UID in the database and matching against it in rules. For a personal single-device deployment the current rules are adequate.

### Authentication Setup

1. In Firebase Console → **Authentication → Sign-in method**, enable **Email/Password**.
2. Under **Authentication → Users**, click **Add user** and create a dedicated device account.
3. Use those credentials in the firmware's `USER_EMAIL` and `USER_PASSWORD` defines.

---

## 🎙️ Voice Commands

Voice control uses the browser's built-in **Web Speech API** (no API key required). Click the **Voice Control** button in the dashboard header, then speak any of the following commands:

| Voice Command | Alternatives | Action |
|---|---|---|
| **"Tell Status"** | "Tank Status", "How is the water" | Reads the current sensor values via TTS and reports whether the aquarium conditions are healthy or critical |
| **"Feed"** | — | Triggers fish feeder immediately — sends `voice_feed` to Firebase |
| **"Pump on"** | "Turn on pump" | Enables manual mode and turns pump ON — sends `voice_pump` to Firebase |
| **"Pump off"** | "Turn off pump" | Enables manual mode and turns pump OFF |
| **"Heater on"** | "Turn on heater" | Enables manual mode and turns heater ON |
| **"Heater off"** | "Turn off heater" | Enables manual mode and turns heater OFF |
| **"Fan on"** | "Turn on fan" | Enables manual mode and turns cooling fan ON |
| **"Fan off"** | "Turn off fan" | Enables manual mode and turns cooling fan OFF |
| **"Lights on"** | "Light on", "Turn on lights" | Turns ARGB tank lights ON |
| **"Lights off"** | "Light off", "Turn off lights" | Turns ARGB tank lights OFF |
| **"Buzzer on"** | "Turn on buzzer" | Manually enables alarm buzzer |
| **"Buzzer off"** | "Turn off buzzer" | Manually disables alarm buzzer |
| **"Auto Mode"** | "Auto" | Switches system to automatic control |
| **"Manual Mode"** | "Manual" | Switches system to manual control |
| **"Test Alert"** | — | Simulates a critical alert (Demo Mode) |
| **"Fix Alert"** | "Reset Alert" | Restores simulated normal conditions (Demo Mode) |

> [!NOTE]
> Voice control requires a browser that supports the Web Speech API (Chrome and Edge recommended). Microphone permission must be granted. The recognition session auto-stops after **15 seconds** of silence, or **5 seconds** after the last detected word. Web Speech API support and behaviour may vary by browser version and operating system — Chrome on desktop provides the most consistent experience.

---

## 🧪 Sensor Calibration

The firmware ships with **Dummy Data mode** for all sensors — ideal for testing the dashboard and Firebase integration without any physical hardware connected. Set the relevant flag to `true` in the firmware:

```cpp
bool DUMMY_PH        = false;   // set true to generate simulated pH readings
bool DUMMY_TDS       = false;
bool DUMMY_TURBIDITY = false;
bool DUMMY_TEMP      = false;
bool DUMMY_BATTERY   = false;
```

### pH Calibration (2-point method)

Perform a standard 2-point calibration using pH 4.0 and pH 7.0 buffer solutions:

1. Dip the probe in **pH 7.0** buffer → note the raw ADC voltage reading from the serial monitor.
2. Dip the probe in **pH 4.0** buffer → note the second ADC voltage reading.
3. Calculate slope and offset from those two readings, then update the firmware:

```cpp
float PH_SLOPE  = -5.70f;   // Volts per pH unit — adjust after calibration
float PH_OFFSET = 21.34f;   // Intercept — adjust after calibration
```

> [!NOTE]
> The default values above (`PH_SLOPE = -5.70`, `PH_OFFSET = 21.34`) are example starting points. Your actual probe will require calibration — results will be inaccurate if you skip this step.

### TDS Calibration

The TDS sensor uses a temperature-compensated formula built into the firmware. For best accuracy, perform the reading in water at a known temperature and compare against a reference TDS meter. Adjust the conversion coefficient in firmware if needed.

### Turbidity Calibration

Turbidity uses a quadratic NTU conversion with a 20-point Simple Moving Average (SMA) for stability. The SMA also drives the degradation trend prediction (days to next filter maintenance). If your sensor module outputs a different voltage curve, update the quadratic coefficients in the firmware.

### Battery Voltage Calibration

The battery voltage is measured via a ×4 resistor divider on GPIO 33. If your resistor values differ slightly, adjust the divider ratio constant in firmware to match your measured real-world voltage.

---

## 🛠️ Troubleshooting

| Symptom | Likely Cause | Fix |
|---|---|---|
| ESP32 won't connect to Wi-Fi | Wrong credentials in `secrets.h` | Double-check `WIFI_SSID` and `WIFI_PASSWORD` — no extra spaces |
| Firebase stream not receiving data | Firebase rules blocking access | Verify security rules and that `USER_EMAIL`/`USER_PASSWORD` match an active Auth user |
| No sensor readings on dashboard | Wiring issue or Dummy Data off | Check GPIO connections against the pin map, or enable Dummy Data mode for testing |
| Temperature always reads 85 °C | DS18B20 power-on sentinel not rejected / wiring fault | Check 1-Wire pull-up resistor (4.7 kΩ on GPIO 25) and sensor wiring |
| pH / TDS / Turbidity readings wildly wrong | Uncalibrated sensor | Perform 2-point calibration — see Sensor Calibration section above |
| Android build fails (Gradle error) | Gradle/SDK mismatch | Run **File → Sync Project with Gradle Files** in Android Studio; ensure SDK 35 is installed |
| Electron app won't start | Missing Node modules | Run `npm install` inside `Windows_App/` before `npm start` |
| Voice commands not recognised | Browser or permission issue | Use Chrome or Edge; grant microphone permission when prompted; ensure Web Speech API is supported on your OS |
| ARGB lights show wrong colour | `light_color` hex not synced | Use the colour picker in the dashboard — it pushes the hex directly to Firebase `/controls/light_color` |
| Heater relay not triggering | Heater hard-disabled due to sensor fault | Check serial monitor for fault messages; verify DS18B20 wiring and that temperature reads correctly |

> [!NOTE]
> For firmware issues, always open the **Arduino IDE Serial Monitor** at **115200 baud** immediately after flashing — the firmware prints detailed startup diagnostics and runtime status every cycle.

---

## ⚡ Electrical Safety

> [!CAUTION]
> **This project involves 240 V AC mains voltage. Incorrect wiring can cause electric shock, fire, or death. Read this section fully before building.**

| Safety Requirement | Details |
|---|---|
| **Qualified person** | All mains-voltage wiring (relay K5, terminals J17/J18) must be connected and tested only by a suitably qualified person |
| **Mains-rated wiring** | Use cable rated ≥ 250 V for all AC sections — correctly sleeved and terminated |
| **Fusing** | Two 5 A / 250 V slow-blow fuses are included in the BOM and PCB layout — always fit them before energising |
| **Enclosure** | House the PCB in an IP-rated enclosure appropriate for the installation environment. Never leave mains terminals exposed |
| **Creepage & clearance** | Maintain the required PCB creepage distances between high-voltage and low-voltage traces — do not bridge them with solder bridges or conductive debris |
| **Low/high voltage separation** | Keep all 240 V AC wiring physically separated from the 5 V / 3.3 V signal wiring at all times |
| **RCD / GFCI protection** | Install an RCD (residual current device) or GFCI on the mains circuit feeding this system — especially important near water |
| **Waterproofing** | The PCB is not waterproof. Protect it from splashes. All sensor probes that enter the aquarium must be rated for submersion |
| **Heater safety cutoff** | The firmware enforces a **30-minute hard cutoff** on the heater relay and disables it on any temperature sensor fault — do not bypass this logic |

**Never power the mains section of the board during firmware development or debugging.** Work with the AC terminals disconnected and use the Dummy Data mode for testing.

---

## 🔩 Hardware & PCB

The custom PCB was designed in **KiCad 10.0.3** as a through-hole friendly layout suitable for DIY etching or professional PCB fabrication.

### PCB Outputs Provided

| Output | Location | Use |
|---|---|---|
| KiCad project files (`.kicad_pcb`, `.kicad_sch`, `.kicad_pro`) | `Hardware/` | Edit in KiCad 10.x |
| Gerber files + drill files | `Hardware/Gerber_Files/` | Send to any PCB fab (JLCPCB, PCBWay, OSH Park…) |
| Zipped Gerber bundle | `Hardware/Gerber_Files/Gerber_ZIP/` | Ready to upload directly to fab ordering page |
| DIY etching PDFs | `Hardware/DIY_Etching_PDFs/` | Toner-transfer / photoresist etching |
| Standard 3D renders (×6) | `Hardware/3D_Models/3D_Standard/` | Documentation / review |
| Raytraced 3D renders (×6) | `Hardware/3D_Models/3D_Raytraced/` | Realistic visual preview |
| Schematic PDF | `Docs/Schematic_Diagram.pdf` | Reference during assembly |

### ESP32 Fit Note

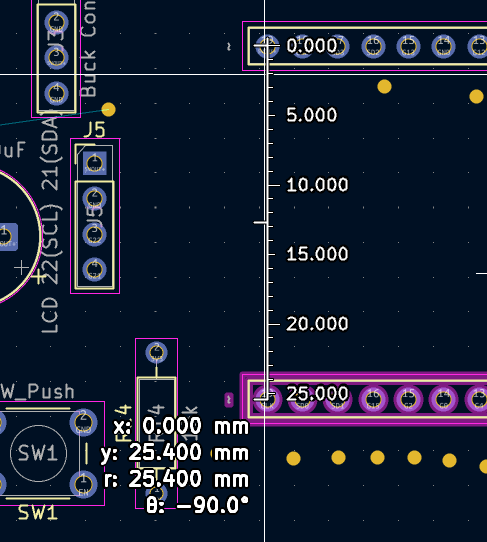
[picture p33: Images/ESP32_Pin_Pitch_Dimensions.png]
ESP32 Dimensions


The PCB accepts a standard **ESP32-WROOM-32 / ESP32-DevKitC 38-pin** module mounted on two 1×19 female pin socket rows.

> [!WARNING]
> The board routes **240 V AC mains** through relay K5 (water heater output). Terminals J17 (AC out) and J18 (AC in) must use mains-rated wiring (≥ 250 V rated, properly sleeved). Observe required creepage distances. This section must only be connected and tested by a qualified person.

---

## 📋 Bill of Materials Summary

Full BOM: [`Docs/Bill_of_Materials.md`](Docs/Bill_of_Materials.md) · CSV: [`Docs/Components_List_BOM.csv`](Docs/Components_List_BOM.csv)

**The hardware design uses exclusively through-hole components to support DIY-friendly assembly.**

| Category | Key Parts |
|---|---|
| Microcontroller | ESP32-WROOM-32 / DevKitC (38-pin) |
| Transistors | BC547 NPN (relay drivers) |
| Relays | SANYOU SRD Form-C (5 V coil, 10 A / 250 VAC) |
| Diodes | SR560 Schottky (4×) · 1N4007 rectifier (4×) · RS505 bridge (1×) | 
| Capacitors | 100 nF ceramic (4×) · 470 µF electrolytic (1×) · 1000 µF (3×) · 10 µF (1×) |
| Resistors | 330 Ω – 30 kΩ (various, ¼ W 5%) |
| Fuses | 5 A / 250 V slow-blow, 5×20 mm |
| Power Module | LM2596 / MP1584 DC-DC buck (12 V → 5 V) |
| Connectors | Screw terminals (5.08 mm) + pin headers (2.54 mm) |
| Switch | 6×6 mm tactile push button (Reset/Boot) |

---

## 🗺️ Roadmap

Planned improvements and ideas for future releases. Community contributions towards any of these are very welcome — see [Contributing](#-contributing).

| Feature | Description | Status |
|---|---|---|
| OTA firmware updates | Push firmware updates to the ESP32 wirelessly via Firebase or a local server | Planned |
| Additional sensor support | Water level sensor, dissolved oxygen (DO), CO₂ | Planned |
| Push notifications | Mobile push alerts via Firebase Cloud Messaging when alarms trigger | Planned |
| Advanced automation rules | User-configurable threshold values stored in Firebase (no reflash required) | Planned |
| Extended analytics | Analytics beyond 21 days; CSV export of historical sensor data | Planned |
| Multi-aquarium support | Extend the Firebase path structure to manage multiple tanks from one dashboard | Planned |
| Role-based Firebase security | Per-path UID-restricted rules (ESP32 write-only to `sensors/status/`, dashboard write-only to `controls/commands/`) | Planned |
| Android: native push notifications | Background service for alarm delivery when the app is not in the foreground | Planned |

> [!NOTE]
> This roadmap reflects current intentions and may change. Items marked **Planned** have not been started. If you have ideas or want to contribute to any of these, open an issue to discuss.

---

## 🤝 Contributing

Contributions are warmly welcomed! Whether it's a bug fix, new feature, improved calibration formula, or documentation update — please feel free to open an issue or pull request.

**Guidelines:**

1. **Fork** the repository and create your branch from `main`.
2. Follow the existing code style — especially the non-blocking `millis()` pattern in firmware (no `delay()` in `loop()`).
3. For dashboard changes, test in both **Demo Mode** and **Firebase Mode**.
4. For hardware changes, verify in KiCad 10.x and update the BOM accordingly.
5. **Never commit real Wi-Fi SSIDs, passwords, or Firebase API keys** — always use placeholder strings.
6. Open a **Pull Request** with a clear description of what was changed and why.

**Reporting Issues:**

Please include your ESP32 core version, Arduino IDE version, and relevant serial output when reporting firmware bugs.

---

## 📜 Licensing

This project utilizes a multi-licensing model to cover software, hardware, and documentation appropriately:

- 💻 **Software & Firmware:** Licensed under the [MIT License](LICENSE) (ESP32 Firmware, Web Dashboard, Android & Windows Apps).
- 🛠️ **Hardware Design:** Licensed under the [CERN-OHL-S-2.0](LICENSE-HARDWARE) (KiCad Schematics & PCB Layouts).
- 📄 **Documentation & Media:** Licensed under [CC BY 4.0](LICENSE-DOCS) (Guides, Images, and Diagrams).

Copyright © 2026 Sachin Rathnayaka (WRSCN)

---

<div align="center">

Made with ❤️ by **[Sachin Rathnayaka (WRSCN)](https://github.com/SachinRathnayaka)**

⭐ If this project helped you, please consider giving it a star on GitHub!



</div>

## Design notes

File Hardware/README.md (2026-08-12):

# Hardware Architecture & KiCad PCB Design

This directory contains the KiCad 10.0 schematic and PCB layout files for the SRAqua Guard Smart Aquarium Automation System.

## License
All hardware schematics, PCB designs, and 3D models in this directory are licensed under the **CERN Open Hardware Licence Version 2 - Strongly Reciprocal (CERN-OHL-S-2.0)**.

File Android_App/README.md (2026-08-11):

# SRAqua Guard Android

Android WebView wrapper for the supplied SRAqua Guard HTML dashboard.

- App name: SRAqua Guard
- Application ID: com.wrscn.sraquaguard
- Portrait orientation
- Internet permission enabled
- Immersive fullscreen
- Dark slate splash theme on Android 12+
- Original `index.html` and `assets/logo.png` bundled under `app/src/main/assets/`

## Build
Open this folder in Android Studio and let Gradle sync, then choose **Build > Build APK(s)**.

No Firebase credentials were added to the project; the supplied HTML keeps its existing setup flow.

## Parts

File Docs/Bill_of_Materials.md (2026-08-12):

# 📋 Bill of Materials (BOM)

**Project:** IoT-Based Smart Aquarium Monitor & Control System  
**Designed by:** Sachin Rathnayaka (WRSCN)  
**Institution:** Sri Lanka Institute of Information Technology (SLIIT)  
**Module:** Fundamentals of Computing (IT1140) — Y1S1  
**Schematic Rev:** 1.0  
**EDA Tool:** KiCad 10.0.3  
**License:** CERN-OHL-S-2.0  
**Repository:** [github.com/SachinRathnayaka/Smart-Aquarium-Monitor-Control-System](https://github.com/SachinRathnayaka/Smart-Aquarium-Monitor-Control-System)  

---

> **Summary:** 41 line items — **74 total components**

> ⚠️ **Safety Warning:** This board includes 240 V AC mains wiring (J17, J18, K5 relay). All high-voltage sections must be handled by a qualified person. Use appropriate insulation, sleeving, and creepage clearances.

---

## 🧠 Microcontrollers  *(×1 total)*

| Reference | Qty | Description | Value / Specs | Package | Notes | Datasheet |
|---|-----|---|---|---|---|---|
| `LEsp32, Resp32` | 1 | ESP32 Development Board (38-pin) | ESP32-WROOM-32 / ESP32-DevKitC | DIP-38 / Module (fits 2× 1×19 female pin socket rows) | Dual-core 240 MHz, Wi-Fi + BT. Two 19-pin female socket rows on PCB. | [link](https://www.espressif.com/sites/default/files/documentation/esp32_datasheet_en.pdf) |

## 🔧 Transistors  *(×4 total)*

| Reference | Qty | Description | Value / Specs | Package | Notes | Datasheet |
|---|-----|---|---|---|---|---|
| `Q1, Q2, Q3, Q4` | 4 | NPN General-Purpose Transistor | BC547 — 45 V, 100 mA | TO-92 Inline | Relay driver stages; Q1=heater relay, Q2=pump relay, Q3=feeder relay, Q4=fan relay. | [link](https://www.onsemi.com/pub/Collateral/BC550-D.pdf) |

## ⚡ Diodes  *(×9 total)*

| Reference | Qty | Description | Value / Specs | Package | Notes | Datasheet |
|---|-----|---|---|---|---|---|
| `D1, D9, D10, D11` | 4 | Schottky Rectifier Diode | SR560 — 60 V, 5 A | DO-41 (SOD81) P10.16mm Horizontal | Flyback / freewheeling diodes across relay coils & motor loads. | [link](http://www.vishay.com/docs/88503/1n4001.pdf) |
| `D2, D12, D13, D14` | 4 | General-Purpose Rectifier Diode | 1N4007 — 1000 V, 1 A | DO-41 (SOD81) P10.16mm Horizontal | Reverse-polarity protection & flyback suppression. | [link](http://www.vishay.com/docs/88503/1n4001.pdf) |
| `D3` | 1 | Bridge Rectifier Module | RS505 — 50 V PIV, 5 A | Diode Bridge 19.0×3.5×10.0mm P5.0mm | Full-wave bridge for AC→DC conversion on main power input. | [link](https://diotec.com/tl_files/diotec/files/pdf/datasheets/b40c2300.pdf) |

## 🔋 Capacitors  *(×9 total)*

| Reference | Qty | Description | Value / Specs | Package | Notes | Datasheet |
|---|-----|---|---|---|---|---|
| `C1, C5` | 2 | Ceramic Disc Capacitor | 100 nF (0.1 µF) — 50 V | C Disc D5.0mm W2.5mm P5.00mm | Bypass / decoupling on power rails. | — |
| `C4, C8` | 2 | Ceramic Disc Capacitor | 100 nF (0.1 µF) — 50 V | C Disc D5.0mm W2.5mm P5.00mm | High-frequency decoupling near relay driver circuits. | — |
| `C2` | 1 | Electrolytic Capacitor (Polarized) | 470 µF — 25 V | CP Radial D8.0mm P3.50mm | Bulk filtering on regulated supply output. | — |
| `C3, C6, C7` | 3 | Electrolytic Capacitor (Polarized) | 1000 µF — 25 V | CP Radial D10.0mm P5.00mm | Main bulk filtering on 12 V and 5 V power rails. | — |
| `C9` | 1 | Electrolytic Capacitor (Polarized) | 10 µF — 25 V | CP Radial D5.0mm P2.00mm | Decoupling / soft-start capacitor. | — |

## 〰️ Resistors  *(×22 total)*

| Reference | Qty | Description | Value / Specs | Package | Notes | Datasheet |
|---|-----|---|---|---|---|---|
| `R5, R7, R9, R10, R20` | 5 | Carbon Film Resistor | 330 Ω — ¼ W, 5% | R Axial DIN0207 L6.3mm D2.5mm P10.16mm Horizontal | Current-limiting resistors for status / indicator LEDs. | — |
| `R3` | 1 | Carbon Film Resistor | 470 Ω — ¼ W, 5% | R Axial DIN0207 L6.3mm D2.5mm P10.16mm Horizontal | Base resistor / LED current limit. | — |
| `R1, R4, R8, R11, R17, R18` | 6 | Carbon Film Resistor | 1 kΩ — ¼ W, 5% | R Axial DIN0207 L6.3mm D2.5mm P10.16mm Horizontal | Transistor base resistors & pull-ups. (Schematic lists as '1Kom' and '1KOHM' — same value.) | — |
| `R6, R12` | 2 | Carbon Film Resistor | 2 kΩ — ¼ W, 5% | R Axial DIN0207 L6.3mm D2.5mm P10.16mm Horizontal | Voltage divider arms (sensor signal conditioning). | — |
| `R2` | 1 | Carbon Film Resistor | 2.2 kΩ — ¼ W, 5% | R Axial DIN0207 L6.3mm D2.5mm P10.16mm Horizontal | pH signal bias / divider. | — |
| `R13, R15, R16` | 3 | Carbon Film Resistor | 3.3 kΩ — ¼ W, 5% | R Axial DIN0207 L6.3mm D2.5mm P10.16mm Horizontal | I²C pull-up resistors (SDA/SCL lines to LCD & RTC). | — |
| `4.7kom1` | 1 | Carbon Film Resistor | 4.7 kΩ — ¼ W, 5% | R Axial DIN0207 L6.3mm D2.5mm P10.16mm Horizontal | DS18B20 temperature sensor 1-Wire pull-up resistor. | — |
| `R14, R19` | 2 | Carbon Film Resistor | 10 kΩ — ¼ W, 5% | R Axial DIN0207 L6.3mm D2.5mm P10.16mm Horizontal | EN/boot pull-up (R14) and BMS sense divider (R19). | — |
| `R21` | 1 | Carbon Film Resistor | 30 kΩ — ¼ W, 5% | R Axial DIN0207 L6.3mm D2.5mm P10.16mm Horizontal | Voltage divider upper arm (battery / solar level sense). | — |

## 🔌 Relays  *(×3 total)*

| Reference | Qty | Description | Value / Specs | Package | Notes | Datasheet |
|---|-----|---|---|---|---|---|
| `K4, K5, K6` | 3 | SPDT Relay — 5 V Coil | SANYOU SRD Series Form-C — 5 V coil, 10 A / 250 VAC contacts | Relay THT SPDT SANYOU SRD Form-C | K4 = Water pump, K5 = Heater (240 V), K6 = Auxiliary fan / cooling. | [link](http://www.sanyourelay.ca/public/products/pdf/SRD.pdf) |

## 🛡️ Fuses  *(×2 total)*

| Reference | Qty | Description | Value / Specs | Package | Notes | Datasheet |
|---|-----|---|---|---|---|---|
| `F1, F2` | 2 | Fuse Holder + Fuse — 5×20 mm | 5 A / 250 V slow-blow (or as per load; see notes) | Fuseholder Cylinder 5×20mm Schurter 0031.8201 Horizontal Open | F1 = Main DC input (12 V line). F2 = Secondary / sensor supply. Use appropriate ratings. | — |

## 🔘 Switchs  *(×1 total)*

| Reference | Qty | Description | Value / Specs | Package | Notes | Datasheet |
|---|-----|---|---|---|---|---|
| `SW1` | 1 | Momentary Push Button (Reset / Boot) | 6 mm × 6 mm tactile push button, SPST-NO | SW_PUSH_6mm THT | Reset button for ESP32. Also used as manual boot trigger (hold during power-on → download mode). | — |

## ⚙️ Power Modules  *(×1 total)*

| Reference | Qty | Description | Value / Specs | Package | Notes | Datasheet |
|---|-----|---|---|---|---|---|
| `J3` | 1 | DC-DC Buck Converter Module (12 V → 5 V) | LM2596 or MP1584 based — Input 12 V, Output 5 V / ≥2 A | 4-pin header 2.54 mm (mounts as sub-module) | Supplies 5 V rail for ESP32, relays, sensors & LCD. Pre-set output before installing. | — |

## 🔗 Connectors  *(×22 total)*

| Reference | Qty | Description | Value / Specs | Package | Notes | Datasheet |
|---|-----|---|---|---|---|---|
| `J1, J4, J12` | 3 | Screw Terminal Block — 3-pin | Pitch 5.08 mm, 15 A / 300 V | TerminalBlock Phoenix MKDS-1.5-3 P5.08mm Horizontal | J1 = Main power in/out bus, J4 = Water pump wiring, J12 = Auxiliary load wiring. | — |
| `J2, J11, J16` | 3 | DC Barrel Jack Terminal — 12 V Input | 2-pin screw terminal, 5.08 mm pitch | TerminalBlock Phoenix MKDS-1.5-2 P5.08mm Horizontal | 12 V DC supply connection points (J2 = main, J11 = backup/pump, J16 = fan/heatsink). | — |
| `J13PSW1` | 1 | 12 V Power Switch / Jack Terminal | 2-pin screw terminal, 5.08 mm pitch | TerminalBlock Phoenix MKDS-1.5-2 P5.08mm Horizontal | Operation mode selector input (Auto / Manual / Emergency OFF switch). | — |
| `J5` | 1 | LCD I²C Header — 4-pin | 2.54 mm pitch pin header, 1×4 | PinHeader 1×04 P2.54mm Vertical | Connects to 16×2 LCD with I²C backpack (PCF8574). Pins: GND, VCC(5V), SDA(G21), SCL(G22). | — |
| `J6` | 1 | Buzzer Header — 2-pin | 2.54 mm pitch pin header, 1×2 | PinHeader 1×02 P2.54mm Vertical | Active buzzer for alarm alerts (5 V). Driven via GPIO G26. | — |
| `J7` | 1 | pH Sensor Header — 3-pin | 2.54 mm pitch pin header, 1×3 | PinHeader 1×03 P2.54mm Vertical | Connects analog pH sensor module (5 V). Signal → G34 (ADC). | — |
| `J8` | 1 | Turbidity Sensor Header — 3-pin | 2.54 mm pitch pin header, 1×3 | PinHeader 1×03 P2.54mm Vertical | Connects turbidity sensor module (5 V). Signal → G32 (ADC). | — |
| `J9` | 1 | Temperature Sensor Header — 3-pin | 2.54 mm pitch pin header, 1×3 | PinHeader 1×03 P2.54mm Vertical | DS18B20 waterproof temperature sensor (3.3 V 1-Wire). Data → G4. | — |
| `J10` | 1 | TDS Sensor Header — 3-pin | 2.54 mm pitch pin header, 1×3 | PinHeader 1×03 P2.54mm Vertical | Total Dissolved Solids sensor module (3.3 V). Analog signal → G35 (ADC). | — |
| `J13` | 1 | Fish Feeder Stepper Motor Terminal — 3-pin | 5.08 mm pitch screw terminal, 1×3 | TerminalBlock Phoenix MKDS-1.5-3 P5.08mm Horizontal | Connects stepper/servo motor for automated fish feeder. Controlled via G17/G16. | — |
| `J14` | 1 | BMS / Battery Monitor Terminal — 2-pin | 5.08 mm pitch screw terminal, 1×2 | TerminalBlock Phoenix MKDS-1.5-2 P5.08mm Horizontal | Battery Management System connection. Battery level sense via G33 (ADC). | — |
| `J15` | 1 | Solar Panel Input Terminal — 2-pin | 5.08 mm pitch screw terminal, 1×2 | TerminalBlock Phoenix MKDS-1.5-2 P5.08mm Horizontal | Solar panel DC input (feeds BMS / battery charging circuit). | — |
| `J17` | 1 | 240 V AC Output Terminal — 2-pin | 5.08 mm pitch screw terminal, 1×2 — rated ≥250 VAC | TerminalBlock Phoenix MKDS-1.5-2 P5.08mm Horizontal | ⚠ HIGH VOLTAGE — Heater controlled by relay K5. Use insulated wiring rated for 240 V AC. | — |
| `J18` | 1 | 240 V AC Input Terminal — 2-pin | 5.08 mm pitch screw terminal, 1×2 — rated ≥250 VAC | TerminalBlock Phoenix MKDS-1.5-2 P5.08mm Horizontal | ⚠ HIGH VOLTAGE — Mains AC input feed through fuse F1 to K5 relay. | — |
| `J19` | 1 | ARGB Lighting Header — 3-pin | 2.54 mm pitch pin header, 1×3 | PinHeader 1×03 P2.54mm Vertical | Stress-free ARGB LED strip connector (5 V). Data → G27. | — |
| `J20` | 1 | Heat Dissipation / Fan Header — 2-pin | 2.54 mm pitch pin header, 1×2 | PinHeader 1×02 P2.54mm Vertical | Auxiliary 12 V cooling fan for heat dissipation unit. Relay K6 controlled. | — |
| `J21` | 1 | General Purpose 8-pin Header | 2.54 mm pitch pin header, 1×8 | PinHeader 1×08 P2.54mm Vertical | Status & power indicator LED array connector (multi-LED bar for 5 V, 12 V, pump, fan, etc.). | — |
| `J22` | 1 | General Purpose 6-pin Socket | 2.54 mm pitch pin socket, 1×6 | PinSocket 1×06 P2.54mm Vertical | RTC DS3231 module socket (3.3 V, I²C). SDA/SCL shared with LCD. | — |

---

## 📦 Consolidated Shopping List

Grouped by value for easy ordering:

### Resistors (all ¼ W, 5%, axial THT)

| Value | Qty | Ref |
|---|-----|-----|
| 330 Ω | 5 | R5, R7, R9, R10, R20 |
| 470 Ω | 1 | R3 |
| 1 kΩ | 6 | R1, R4, R8, R11, R17, R18 |
| 2 kΩ | 2 | R6, R12 |
| 2.2 kΩ | 1 | R2 |
| 3.3 kΩ | 3 | R13, R15, R16 |
| 4.7 kΩ | 1 | 4.7kom1 |
| 10 kΩ | 2 | R14, R19 |
| 30 kΩ | 1 | R21 |

### Capacitors (THT)

| Value | Type | Qty | Ref |
|---|---|-----|-----|
| 100 nF (0.1 µF) | Ceramic disc | 2 | `C1, C5` |
| 100 nF (0.1 µF) | Ceramic disc | 2 | `C4, C8` |
| 470 µF | Electrolytic (polarized) | 1 | `C2` |
| 1000 µF | Electrolytic (polarized) | 3 | `C3, C6, C7` |
| 10 µF | Electrolytic (polarized) | 1 | `C9` |

### Other Components

| Component | Value / Part No. | Qty |
|---|---|-----|
| ESP32 Development Board (38-pin) | ESP32-WROOM-32 / ESP32-DevKitC | 1 |
| NPN General-Purpose Transistor | BC547 | 4 |
| Schottky Rectifier Diode | SR560 | 4 |
| General-Purpose Rectifier Diode | 1N4007 | 4 |
| Bridge Rectifier Module | RS505 | 1 |
| SPDT Relay — 5 V Coil | SANYOU SRD Series Form-C | 3 |
| Fuse Holder + Fuse — 5×20 mm | 5 A / 250 V slow-blow (or as per load; see notes) | 2 |
| Momentary Push Button (Reset / Boot) | 6 mm × 6 mm tactile push button, SPST-NO | 1 |
| DC-DC Buck Converter Module (12 V → 5 V) | LM2596 or MP1584 based | 1 |

---

*Generated from KiCad schematic. Cross-check with the latest `.kicad_sch` file before ordering.*

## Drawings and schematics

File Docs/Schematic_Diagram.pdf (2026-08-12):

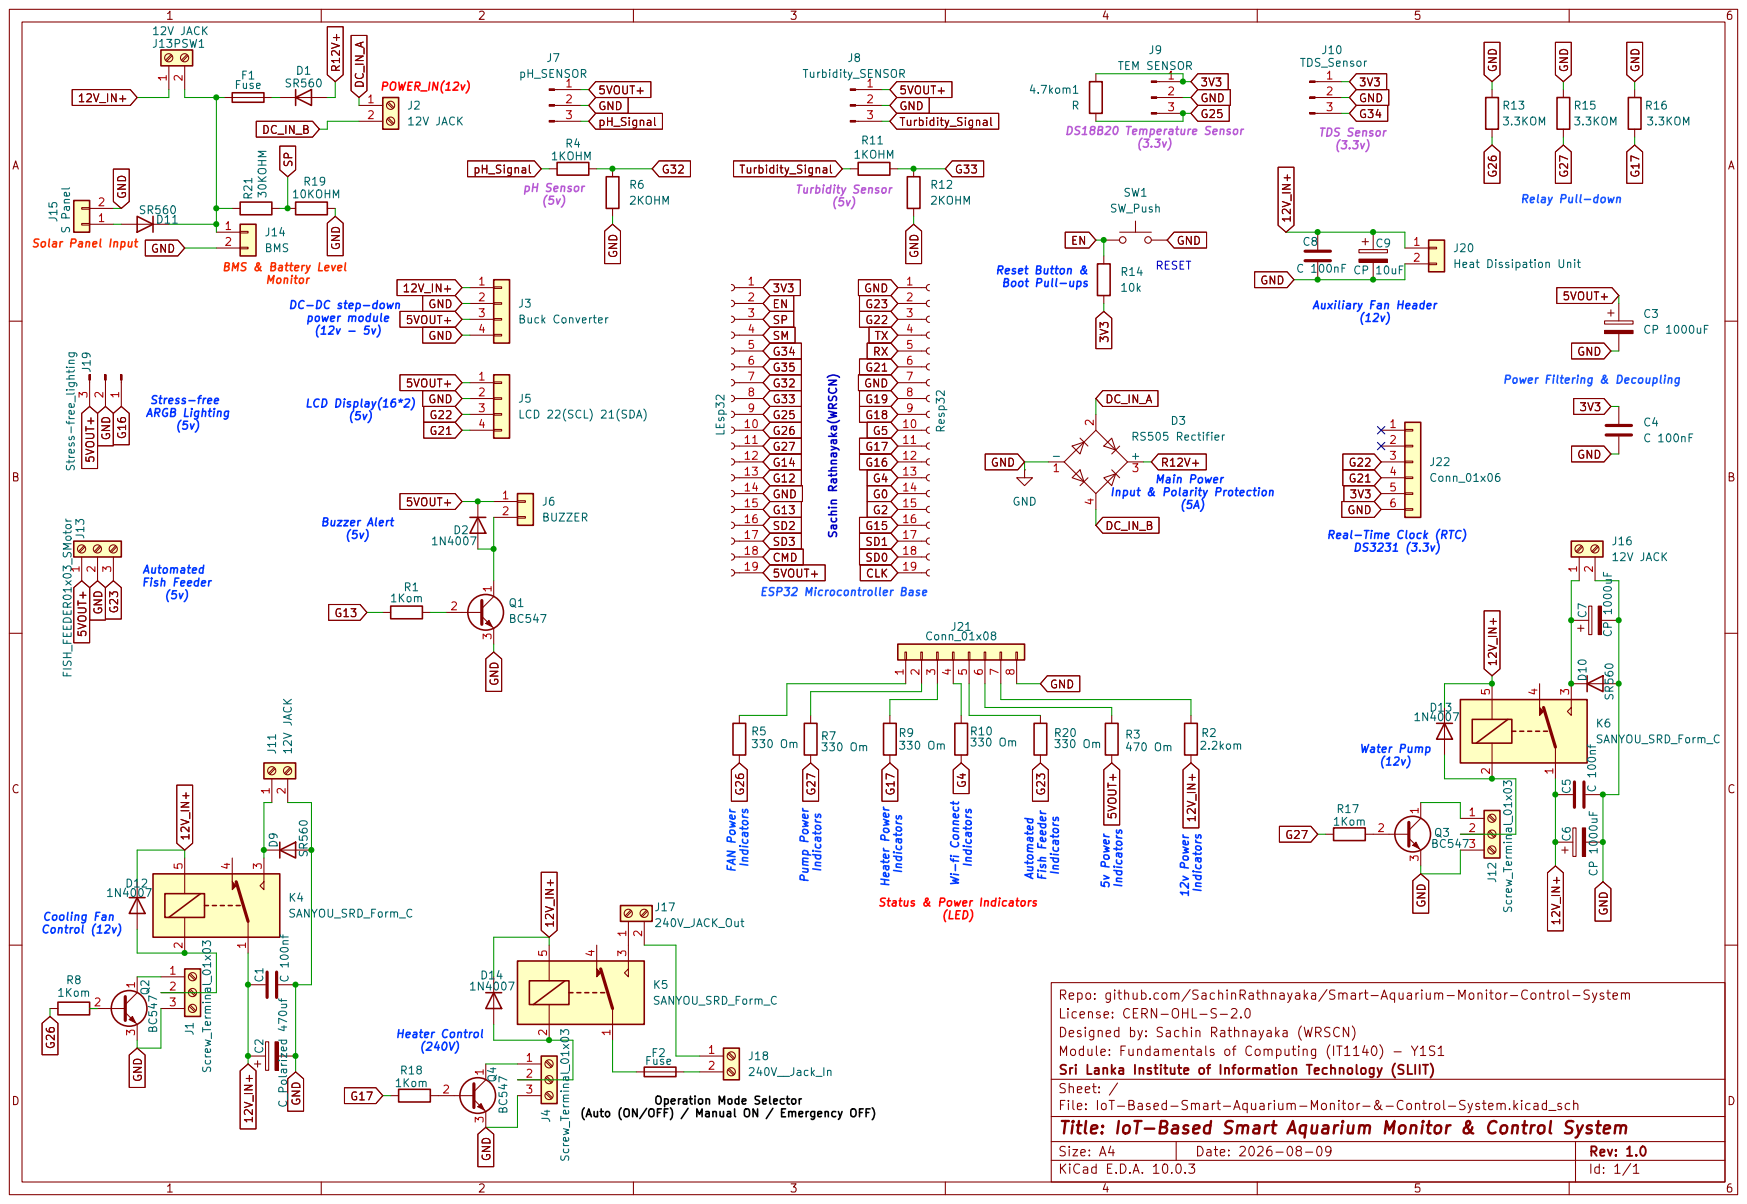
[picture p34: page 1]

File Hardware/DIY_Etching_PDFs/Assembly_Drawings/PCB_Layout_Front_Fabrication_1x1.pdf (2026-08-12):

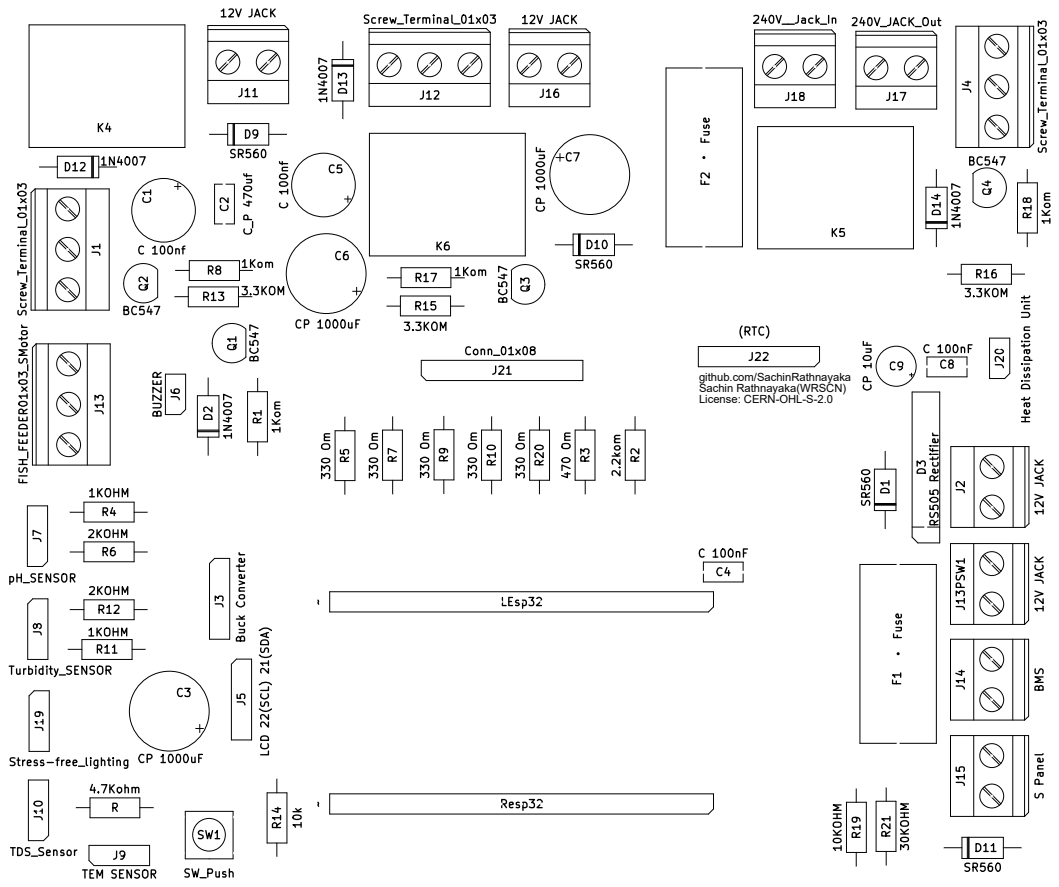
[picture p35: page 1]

github.com/SachinRathnayaka
Sachin Rathnayaka(WRSCN)
License: CERN-OHL-S-2.0

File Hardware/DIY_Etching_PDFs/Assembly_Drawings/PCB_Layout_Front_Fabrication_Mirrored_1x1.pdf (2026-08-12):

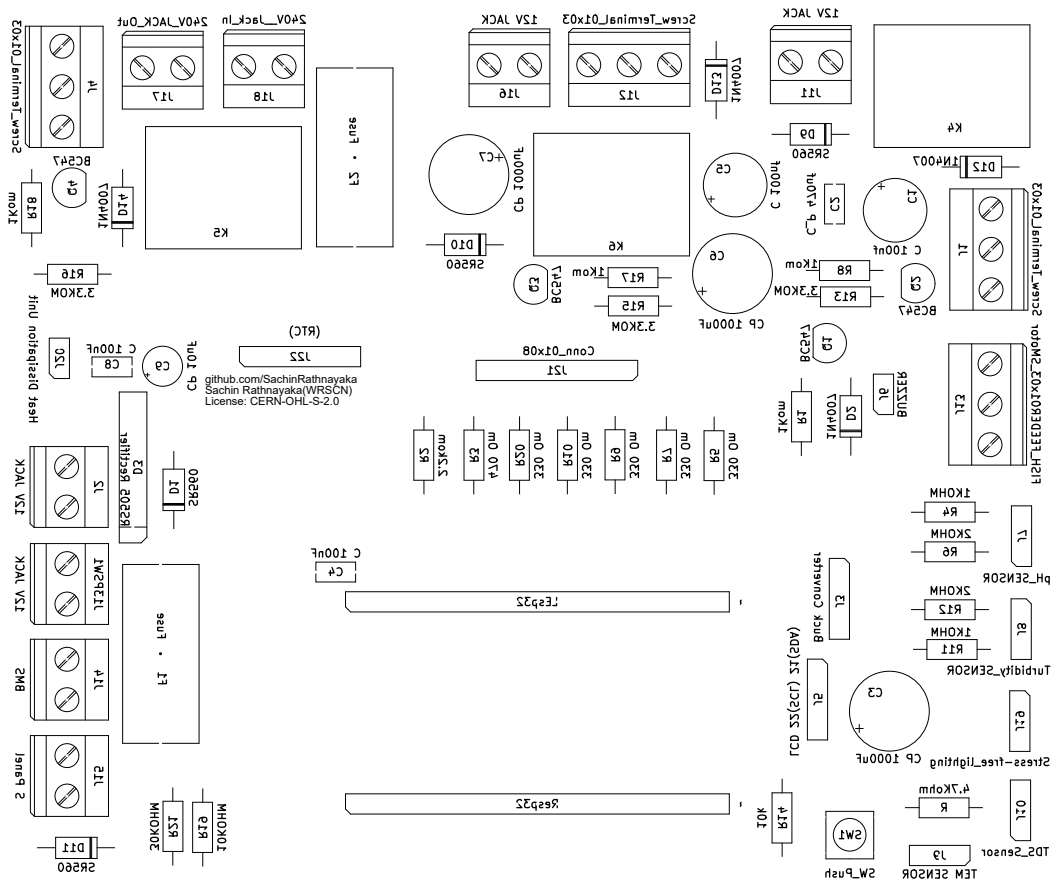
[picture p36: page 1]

github.com/SachinRathnayaka
Sachin Rathnayaka(WRSCN)
License: CERN-OHL-S-2.0

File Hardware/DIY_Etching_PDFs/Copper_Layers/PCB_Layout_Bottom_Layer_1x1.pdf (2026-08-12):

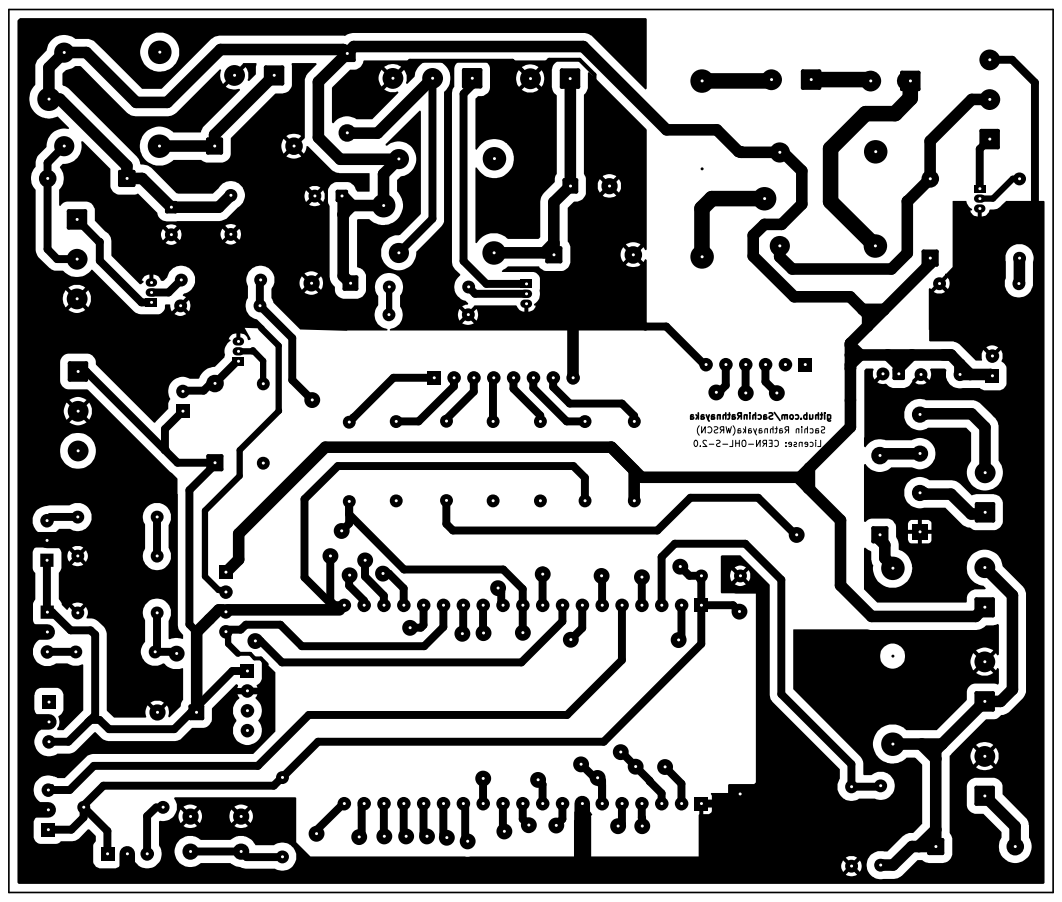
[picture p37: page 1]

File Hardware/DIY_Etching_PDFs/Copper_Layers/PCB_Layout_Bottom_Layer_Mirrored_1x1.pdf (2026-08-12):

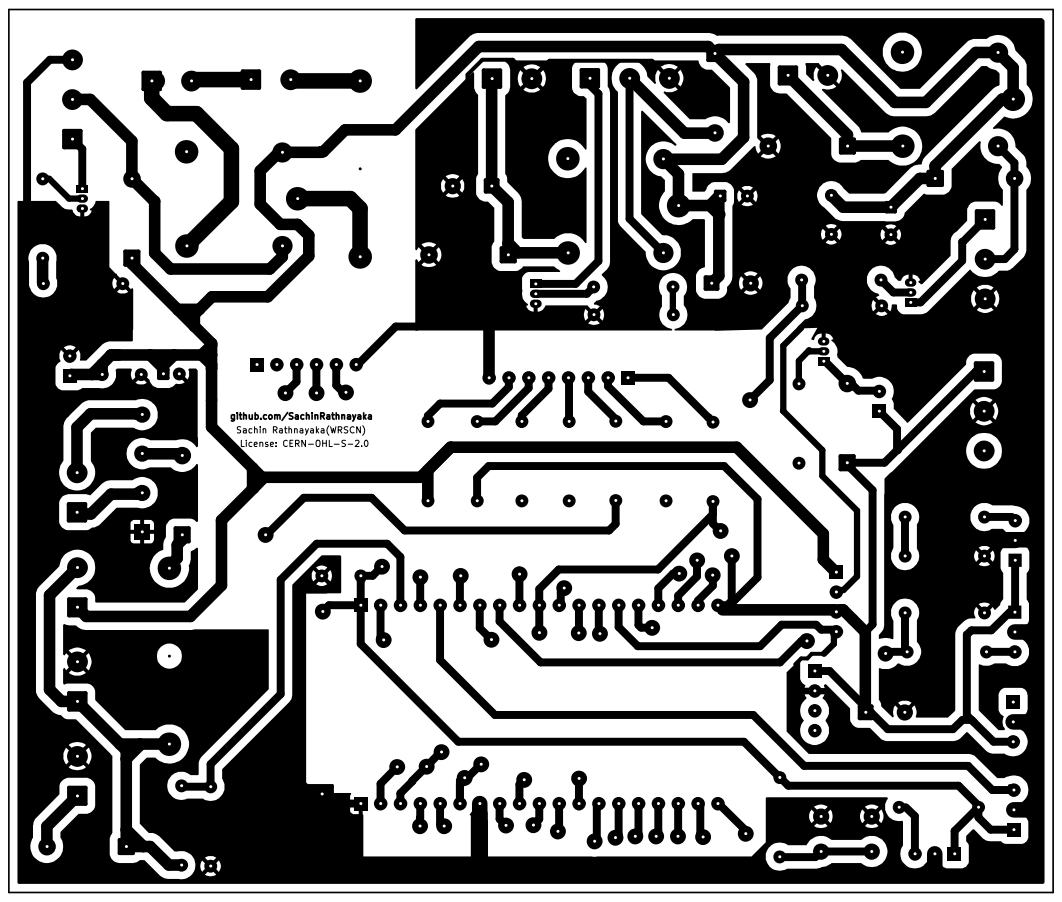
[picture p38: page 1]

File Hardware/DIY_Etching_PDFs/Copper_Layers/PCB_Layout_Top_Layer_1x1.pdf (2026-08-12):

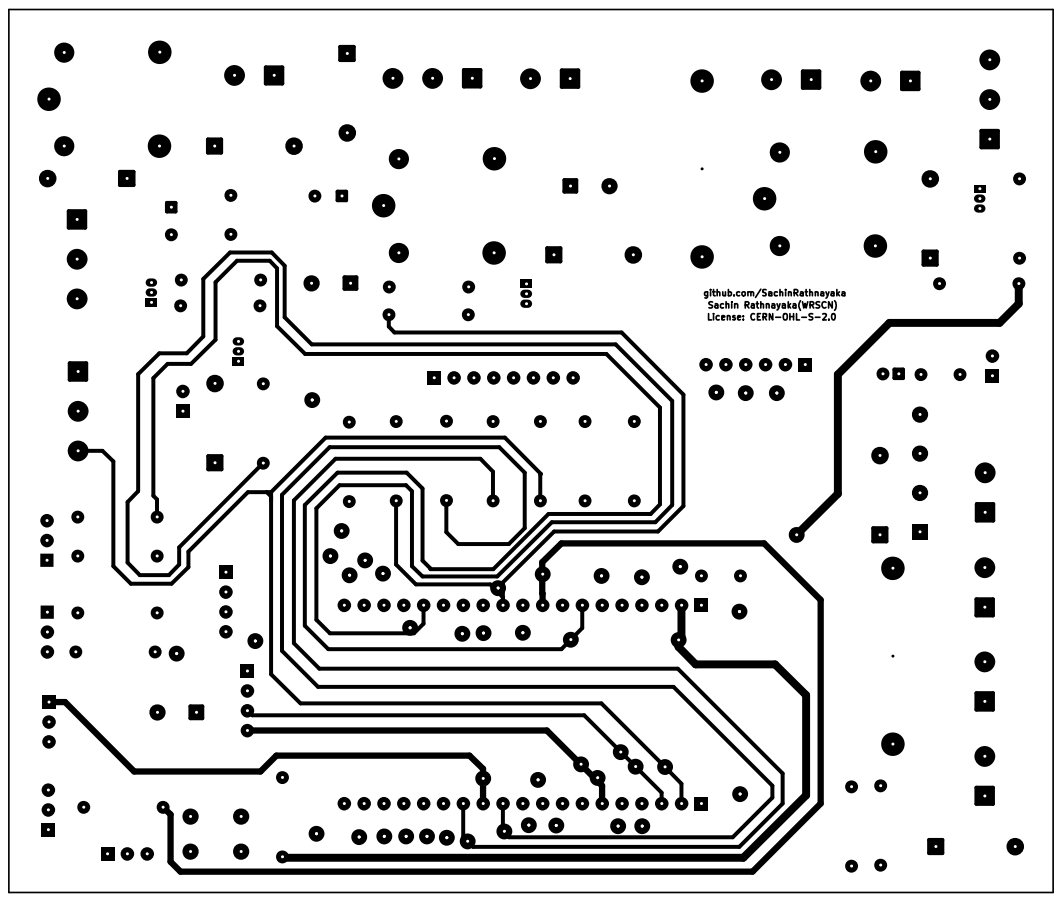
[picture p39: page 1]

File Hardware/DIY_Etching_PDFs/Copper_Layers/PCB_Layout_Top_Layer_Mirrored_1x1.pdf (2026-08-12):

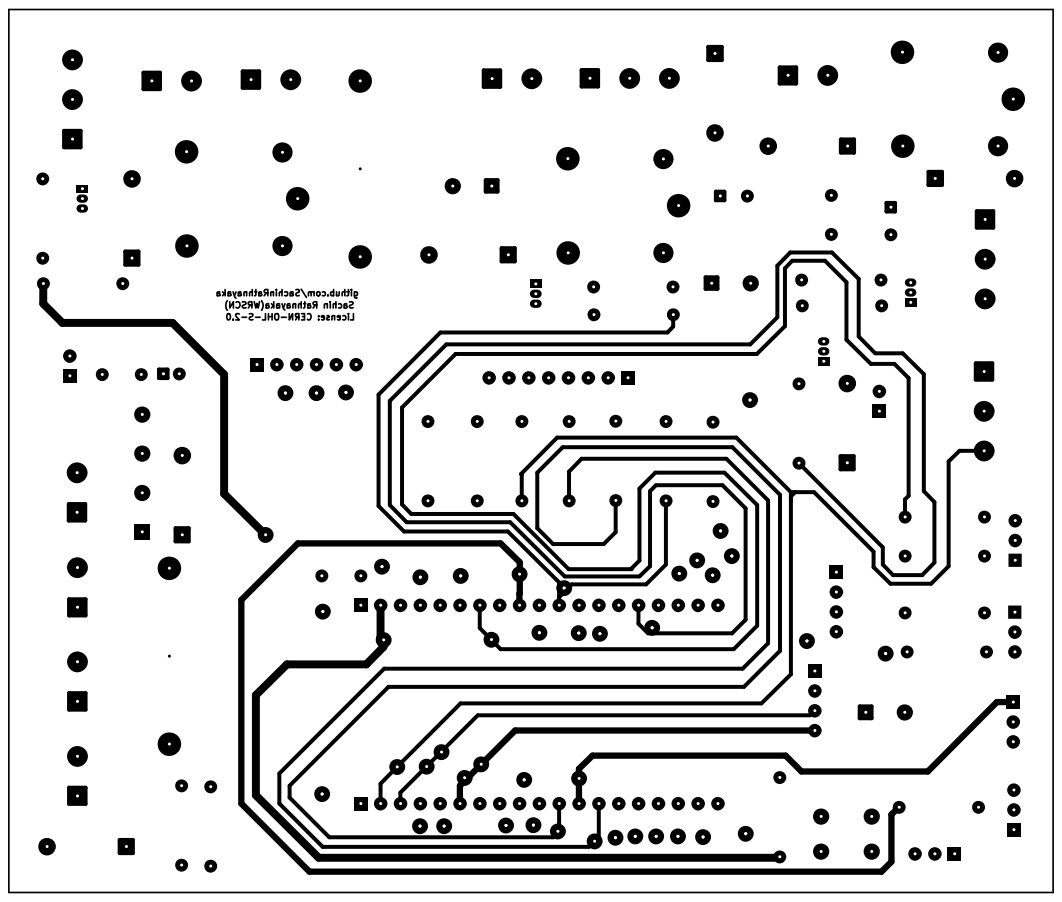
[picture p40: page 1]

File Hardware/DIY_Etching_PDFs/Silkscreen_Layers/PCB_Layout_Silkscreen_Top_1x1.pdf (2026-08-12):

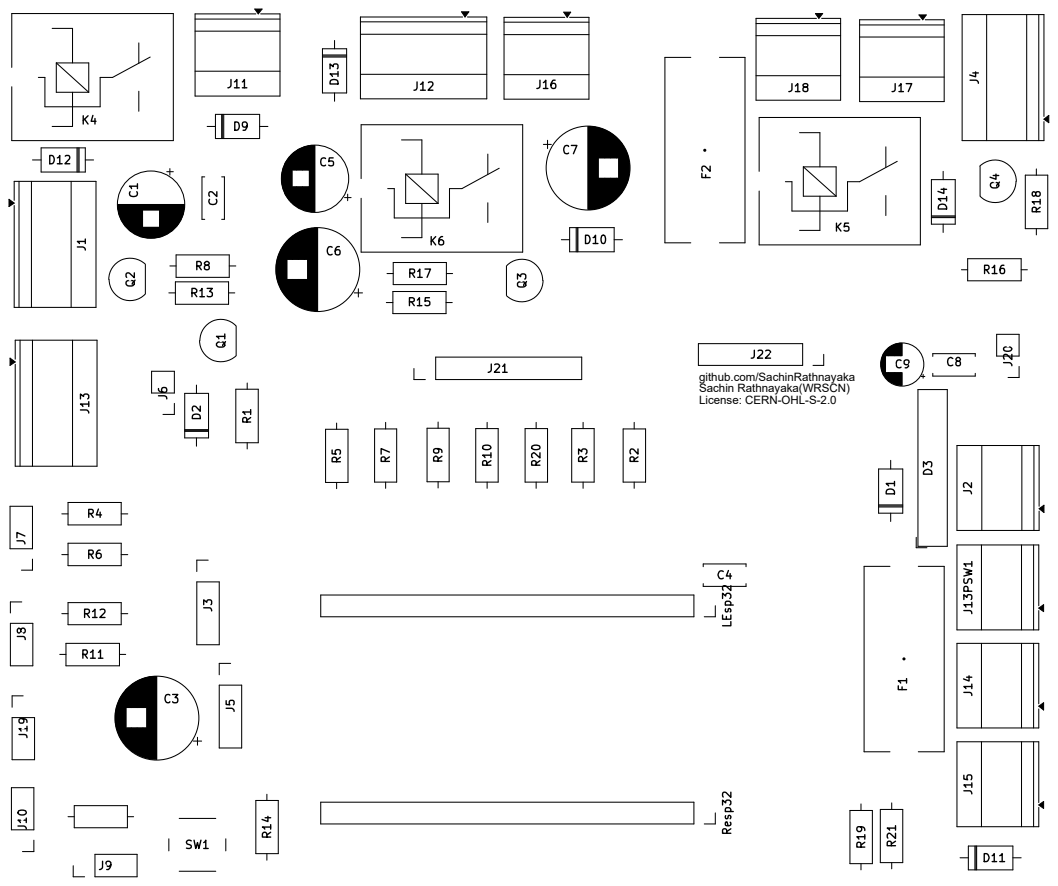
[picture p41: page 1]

github.com/SachinRathnayaka
Sachin Rathnayaka(WRSCN)
License: CERN-OHL-S-2.0

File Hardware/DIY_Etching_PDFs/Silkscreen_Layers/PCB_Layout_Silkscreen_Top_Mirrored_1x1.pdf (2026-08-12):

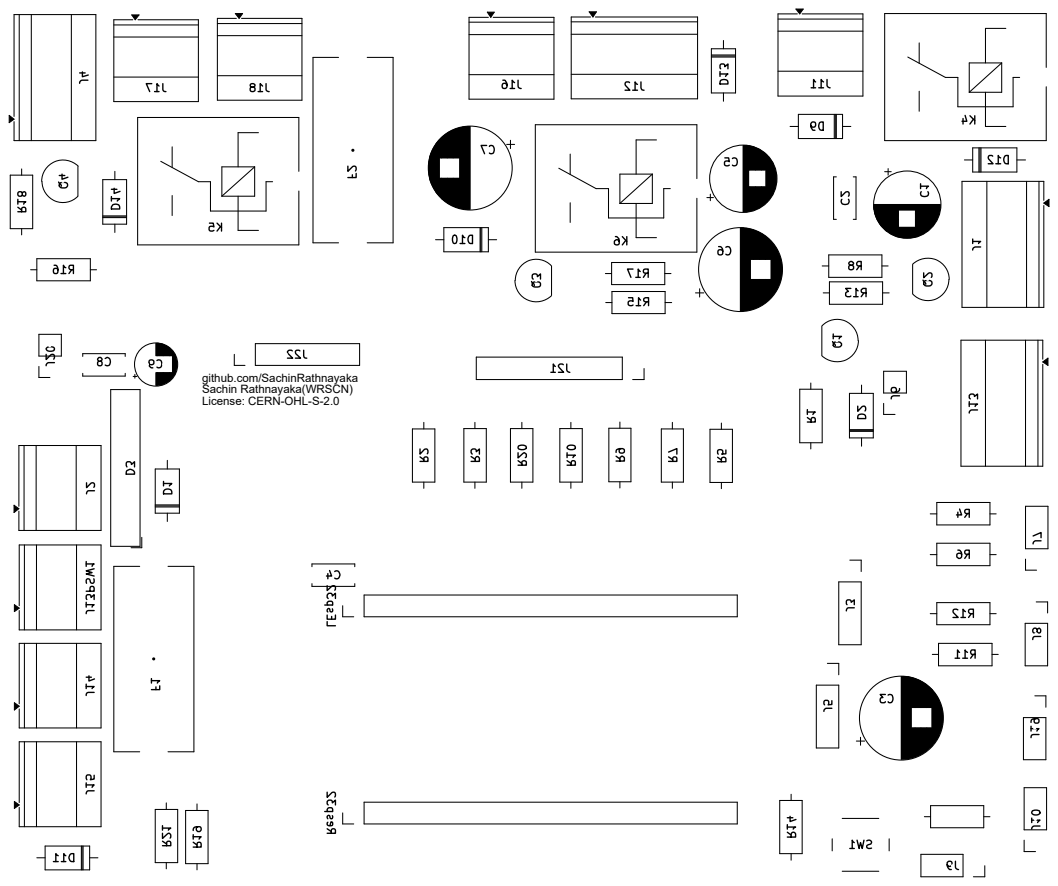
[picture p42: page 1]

github.com/SachinRathnayaka
Sachin Rathnayaka(WRSCN)
License: CERN-OHL-S-2.0

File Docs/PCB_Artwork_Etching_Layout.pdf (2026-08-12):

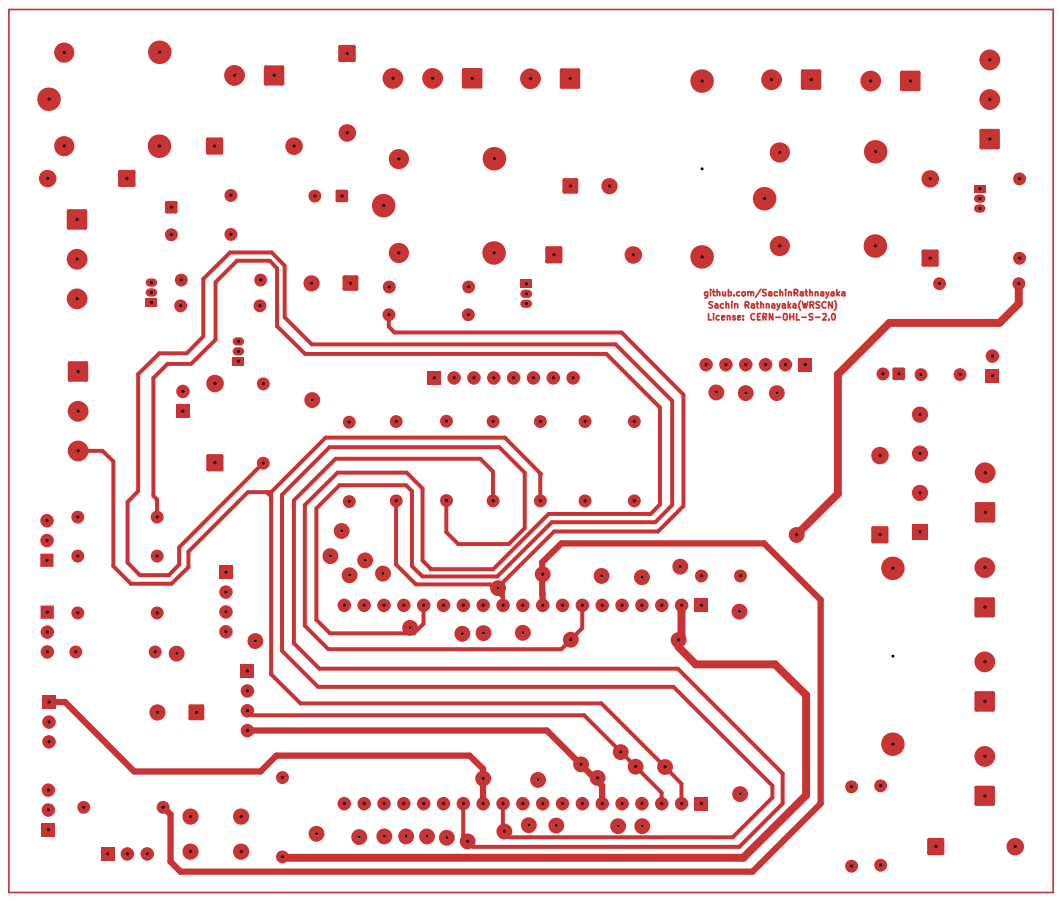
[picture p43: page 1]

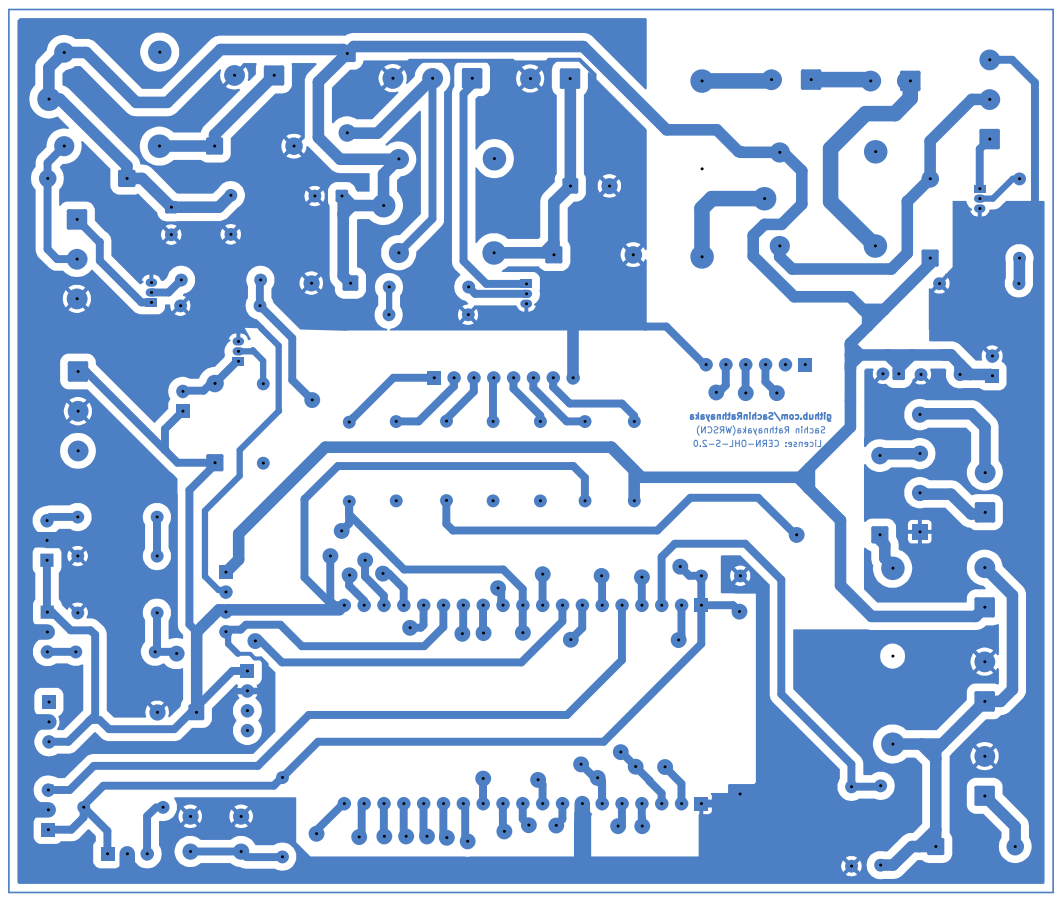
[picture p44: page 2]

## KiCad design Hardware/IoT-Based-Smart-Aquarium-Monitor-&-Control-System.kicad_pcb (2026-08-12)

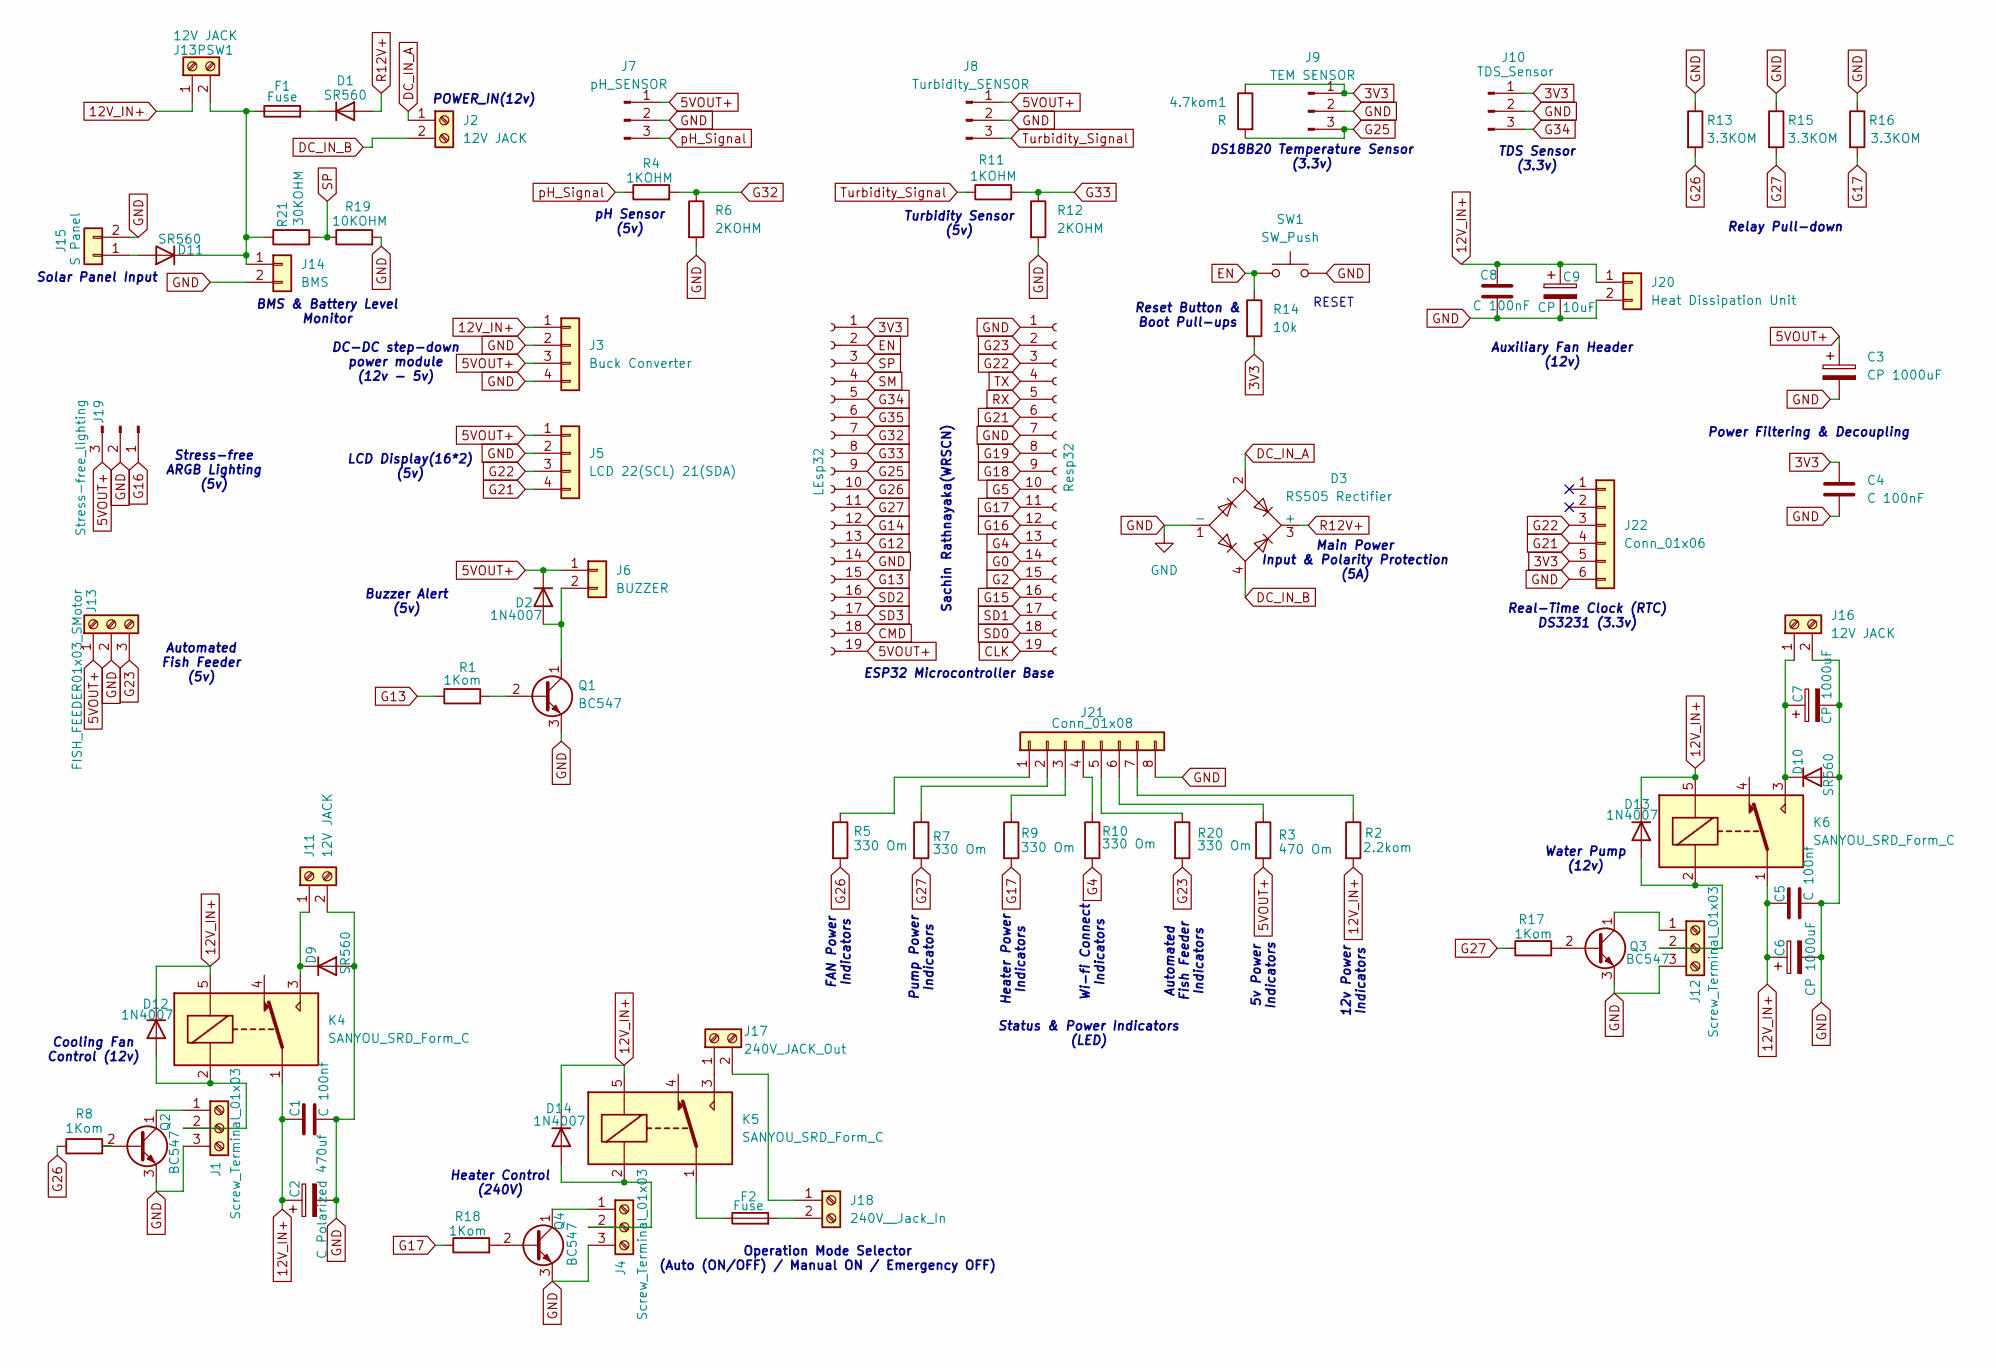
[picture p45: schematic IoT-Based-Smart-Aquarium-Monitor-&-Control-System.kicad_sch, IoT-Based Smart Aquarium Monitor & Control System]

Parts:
4.7kom1: R; R_Axial_DIN0207_L6.3mm_D2.5mm_P10.16mm_Horizontal
C1, C5: C 100nf; CP_Radial_D8.0mm_P3.50mm
C2: C_Polarized 470uf; C_Disc_D5.0mm_W2.5mm_P5.00mm
C3, C6, C7: CP 1000uF; CP_Radial_D10.0mm_P5.00mm
C4, C8: C 100nF; C_Disc_D5.0mm_W2.5mm_P5.00mm
C9: CP 10uF; CP_Radial_D5.0mm_P2.00mm
D1, D9, D10, D11: SR560; D_DO-41_SOD81_P10.16mm_Horizontal
D2, D12, D13, D14: 1N4007; D_DO-41_SOD81_P10.16mm_Horizontal
D3: RS505 Rectifier; Diode_Bridge_19.0x3.5x10.0mm_P5.0mm
F1, F2: Fuse; Fuseholder_Cylinder-5x20mm_Schurter_0031_8201_Horizontal_Op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
J1, J4, J12: Screw_Terminal_01x03; TerminalBlock_Phoenix_MKDS-1,5-3-5.08_1x03_P5.08mm_Horizont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
J2, J11, J13PSW1, J16: 12V JACK; TerminalBlock_Phoenix_MKDS-1,5-2-5.08_1x02_P5.08mm_Horizont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
J3: Buck Converter; PinHeader_1x04_P2.54mm_Vertical
J5: LCD 22(SCL) 21(SDA); PinHeader_1x04_P2.54mm_Vertical
J6: BUZZER; PinHeader_1x02_P2.54mm_Vertical
J7: pH_SENSOR; PinHeader_1x03_P2.54mm_Vertical
J8: Turbidity_SENSOR; PinHeader_1x03_P2.54mm_Vertical
J9: TEM SENSOR; PinHeader_1x03_P2.54mm_Vertical
J10: TDS_Sensor; PinHeader_1x03_P2.54mm_Vertical
J13: FISH_FEEDER01x03_SMotor; TerminalBlock_Phoenix_MKDS-1,5-3-5.08_1x03_P5.08mm_Horizont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
J14: BMS; TerminalBlock_Phoenix_MKDS-1,5-2-5.08_1x02_P5.08mm_Horizont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
J15: S Panel; TerminalBlock_Phoenix_MKDS-1,5-2-5.08_1x02_P5.08mm_Horizont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
J17: 240V_JACK_Out; TerminalBlock_Phoenix_MKDS-1,5-2-5.08_1x02_P5.08mm_Horizont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
J18: 240V__Jack_In; TerminalBlock_Phoenix_MKDS-1,5-2-5.08_1x02_P5.08mm_Horizont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
J19: Stress-free_lighting; PinHeader_1x03_P2.54mm_Vertical
J20: Heat Dissipation Unit; PinHeader_1x02_P2.54mm_Vertical
J21: Conn_01x08; PinHeader_1x08_P2.54mm_Vertical
J22: Conn_01x06; PinSocket_1x06_P2.54mm_Vertical
K4, K5, K6: SANYOU_SRD_Form_C; Relay_SPDT_SANYOU_SRD_Series_Form_C
LEsp32: PinSocket_1x19_P2.54mm_Vertical
Q1, Q2, Q3, Q4: BC547; TO-92_Inline
R1, R8, R17, R18: 1Kom; R_Axial_DIN0207_L6.3mm_D2.5mm_P10.16mm_Horizontal
R2: 2.2kom; R_Axial_DIN0207_L6.3mm_D2.5mm_P10.16mm_Horizontal
R3: 470 Om; R_Axial_DIN0207_L6.3mm_D2.5mm_P10.16mm_Horizontal
R4, R11: 1KOHM; R_Axial_DIN0207_L6.3mm_D2.5mm_P10.16mm_Horizontal
R5, R7, R9, R10, R20: 330 Om; R_Axial_DIN0207_L6.3mm_D2.5mm_P10.16mm_Horizontal
R6, R12: 2KOHM; R_Axial_DIN0207_L6.3mm_D2.5mm_P10.16mm_Horizontal
R13, R15, R16: 3.3KOM; R_Axial_DIN0207_L6.3mm_D2.5mm_P10.16mm_Horizontal
R14: 10k; R_Axial_DIN0207_L6.3mm_D2.5mm_P10.16mm_Horizontal
R19: 10KOHM; R_Axial_DIN0207_L6.3mm_D2.5mm_P10.16mm_Horizontal
R21: 30KOHM; R_Axial_DIN0207_L6.3mm_D2.5mm_P10.16mm_Horizontal
Resp32: PinSocket_1x19_P2.54mm_Vertical
SW1: SW_Push; SW_PUSH_6mm

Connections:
3V3: 4.7kom1.1, C4.1, J9.1, J10.1, J22.5, LEsp32.1, R14.2
5VOUT+: C3.1, D2.1 (K), J3.3, J5.1, J6.1, J7.1, J8.1, J13.1, J19.3, LEsp32.19, R3.2
12V_IN+: C1.1, C2.1, C5.1, C6.1, C8.1, C9.1, D12.1 (K), D13.1 (K), D14.1 (K), J3.1, J13PSW1.1, J20.1, K4.1, K4.5, K5.5, K6.1, K6.5, R2.2
CLK: Resp32.19
CMD: LEsp32.18
DC_IN_A: D3.2, J2.1
DC_IN_B: D3.4, J2.2
EN: LEsp32.2, R14.1, SW1.1
G0: Resp32.14
G2: Resp32.15
G4: R10.2, Resp32.13
G5: Resp32.10
G12: LEsp32.13
G13: LEsp32.15, R1.1
G14: LEsp32.12
G15: Resp32.16
G16: J19.1, Resp32.12
G17: R9.2, R16.2, R18.1, Resp32.11
G18: Resp32.9
G19: Resp32.8
G21: J5.4, J22.4, Resp32.6
G22: J5.3, J22.3, Resp32.3
G23: J13.3, R20.2, Resp32.2
G25: 4.7kom1.2, J9.3, LEsp32.9
G26: LEsp32.10, R5.2, R8.1, R13.2
G27: LEsp32.11, R7.2, R15.2, R17.1
G32: LEsp32.7, R4.2, R6.1
G33: LEsp32.8, R11.2, R12.1
G34: J10.3, LEsp32.5
G35: LEsp32.6
GND: C1.2, C2.2, C3.2, C4.2, C5.2, C6.2, C7.2, C8.2, C9.2, D3.1 (-), D9.2 (A), D10.2 (A), J1.3, J3.2, J3.4, J4.3, J5.2, J7.2, J8.2, J9.2, J10.2, J11.2, J12.3, J13.2, J14.2, J15.2, J16.2, J19.2, J20.2, J21.8, J22.6, LEsp32.14, Q1.3 (E), Q2.3 (E), Q3.3 (E), Q4.3 (E), R6.2, R12.2, R13.1, R15.1, R16.1, R19.2, Resp32.1, Resp32.7, SW1.2
unnamed: D1.1 (K), F1.2
unnamed: D2.2 (A), J6.2, Q1.1 (C)
unnamed: D9.1 (K), J11.1, K4.3
unnamed: C7.1, D10.1 (K), J16.1, K6.3
unnamed: D11.2 (A), J15.1
unnamed: D11.1 (K), F1.1, J13PSW1.2, J14.1, R21.1
unnamed: D12.2 (A), J1.2, K4.2
unnamed: D13.2 (A), J12.2, K6.2
unnamed: D14.2 (A), J4.2, K5.2
unnamed: F2.1, K5.1
unnamed: J1.1, Q2.1 (C)
unnamed: J4.1, Q4.1 (C)
unnamed: J12.1, Q3.1 (C)
unnamed: J17.1, K5.3
unnamed: J17.2, J18.1
unnamed: F2.2, J18.2
unnamed: J21.1, R5.1
unnamed: J21.2, R7.1
unnamed: J21.3, R9.1
unnamed: J21.4, R10.1
unnamed: J21.5, R20.1
unnamed: J21.6, R3.1
unnamed: J21.7, R2.1
unnamed: Q1.2 (B), R1.2
unnamed: Q2.2 (B), R8.2
unnamed: Q3.2 (B), R17.2
unnamed: Q4.2 (B), R18.2
R12V+: D1.2 (A), D3.3 (+)
RX: Resp32.5
SD0: Resp32.18
SD1: Resp32.17
SD2: LEsp32.16
SD3: LEsp32.17
SM: LEsp32.4
SP: LEsp32.3, R19.1, R21.2
TX: Resp32.4
Turbidity_Signal: J8.3, R11.1
pH_Signal: J7.3, R4.1

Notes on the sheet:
RESET
pH Sensor (5v)
Heater Power Indicators
Power Filtering & Decoupling
Heater Control (240V)
Automated Fish Feeder (5v)
Turbidity Sensor (5v)
FAN Power Indicators
Auxiliary Fan Header (12v)
Main Power Input & Polarity Protection (5A)
Automated Fish Feeder Indicators
Stress-free ARGB Lighting (5v)
Solar Panel Input
BMS & Battery Level Monitor
Relay Pull-down
Cooling Fan Control (12v)
LCD Display(16*2) (5v)
Sachin Rathnayaka(WRSCN)
Operation Mode Selector (Auto (ON/OFF) / Manual ON / Emergency OFF)
Status & Power Indicators (LED)
5v Power Indicators
DC-DC step-down power module (12v - 5v)
Buzzer Alert (5v)
TDS Sensor (3.3v)
Water Pump (12v)
POWER_IN(12v)
Wi-fi Connect Indicators
DS18B20 Temperature Sensor (3.3v)
Real-Time Clock (RTC) DS3231 (3.3v)
12v Power Indicators
Pump Power Indicators
ESP32 Microcontroller Base
Reset Button & Boot Pull-ups

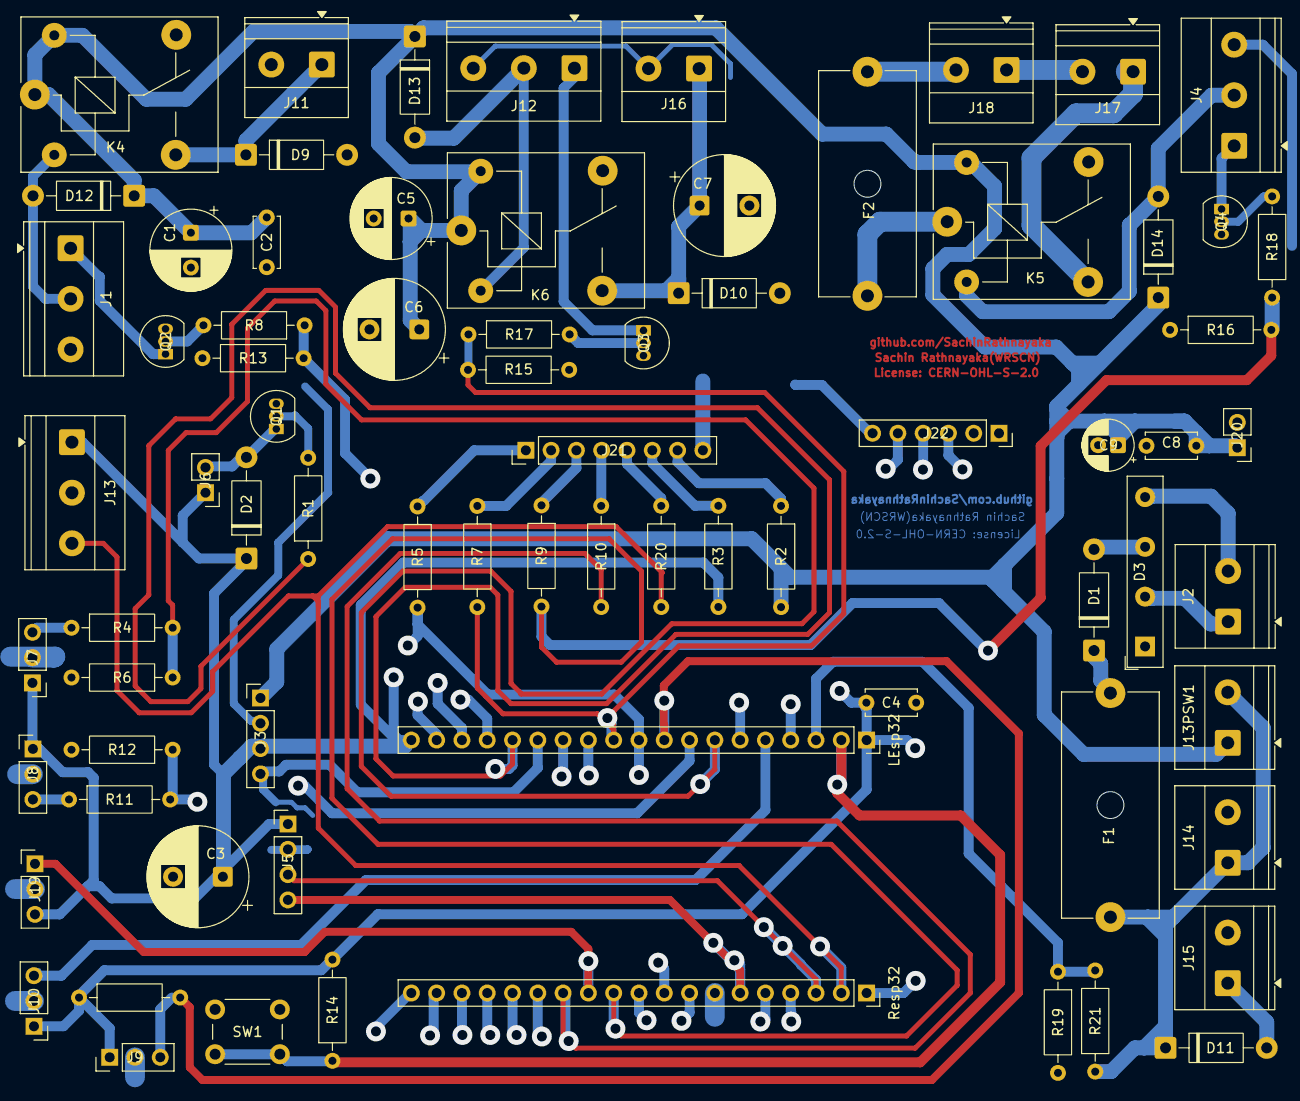
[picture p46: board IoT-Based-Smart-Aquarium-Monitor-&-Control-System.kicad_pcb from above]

Board: 2 copper layers, 75 parts (0 on the bottom side), 51 nets.

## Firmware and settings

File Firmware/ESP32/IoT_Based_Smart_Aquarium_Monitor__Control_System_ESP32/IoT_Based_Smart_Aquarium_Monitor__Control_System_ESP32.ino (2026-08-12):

/*
  ===============================================================
  IoT Based Smart Aquarium Monitor & Control System (ESP32) - Production
  ===============================================================

  Hardware mapping strictly follows your latest schematic request:

  - pH Sensor (Analog)                 : GPIO 34
  - TDS Sensor (Analog)                : GPIO 35
  - Turbidity Sensor (Analog)          : GPIO 32
  - DS18B20 Temp Sensor (OneWire)      : GPIO 25
  - BMS Battery Sense (Analog)         : GPIO 33
  - Cooling Fan Relay                  : GPIO 26
  - Water Pump Relay                   : GPIO 27
  - Heater Relay                       : GPIO 17
  - Fish Feeder Servo                  : GPIO 23
  - ARGB LED Data                      : GPIO 16
  - Buzzer                             : GPIO 13
  - I2C SDA                            : GPIO 21
  - I2C SCL                            : GPIO 22
  - Wi-Fi/Firebase Status LED          : GPIO 4

  

  Key features:
  - Fully non-blocking millis() architecture in loop()
  - DS3231 RTC is the only time source for time-based behavior (offline-safe)
  - Offline auto mode continues sensor/read/control/LCD even without Wi-Fi/Firebase
  - ARGB day-cycle lighting via RTC (morning/day/night breathing)
  - Firebase RTDB control stream + dedicated /commands voice hooks
  - Local web dashboard (port 80) + fish feeding button
  - Filter change alert after 2h pump runtime due to turbidity not improving
  - Auto water-change sequence on critical TDS (max 8 minutes safeguard)
  - Turbidity SMA + degradation trend prediction (days to maintenance)
  - Solar charging inference from battery voltage trend
  - Deep sleep every 5 mins during battery-only condition (loads safely off)
  - Dummy data switches for dry test (uncalibrated sensors)

  ---------------------------------------------------------------
  REQUIRED LIBRARIES (Arduino Library Manager):
  ---------------------------------------------------------------
  - Firebase ESP Client by mobizt
  - LiquidCrystal I2C
  - DallasTemperature
  - OneWire
  - RTClib
  - FastLED
  - ESP32Servo

  ---------------------------------------------------------------
  SECURITY NOTE:
  ---------------------------------------------------------------
  Credentials below are placeholders only. Fill your own values.
*/

#include <WiFi.h>
#include <WebServer.h>
#include <Wire.h>
#include <LiquidCrystal_I2C.h>
#include <OneWire.h>
#include <DallasTemperature.h>
#include <RTClib.h>
#include <FastLED.h>
#include <ESP32Servo.h>
#include <Firebase_ESP_Client.h>
#include "addons/TokenHelper.h"
#include "addons/RTDBHelper.h"

// ---------------------------------------------------------------
// ESP32 Arduino Core 3.x compatibility
// Core 2.x used ADC_11db; Core 3.x renamed it ADC_ATTEN_DB_12.
// ---------------------------------------------------------------
#ifndef ADC_11db
  #define ADC_11db ADC_ATTEN_DB_12
#endif

// =======================================================
// 1) CENTRALIZED PIN CONFIGURATION (STRICT)
// =======================================================
#define PH_SENSOR_PIN            34
#define TDS_SENSOR_PIN           35
#define TURBIDITY_SENSOR_PIN     32
#define TEMP_SENSOR_PIN          25
#define BMS_BATTERY_PIN          33

#define FAN_RELAY_PIN            26
#define PUMP_RELAY_PIN           27
#define HEATER_RELAY_PIN         17
#define FEEDER_SERVO_PIN         23
#define ARGB_DATA_PIN            16
#define BUZZER_PIN               13
#define WIFI_STATUS_LED_PIN      4

#define I2C_SDA_PIN              21
#define I2C_SCL_PIN              22

// =======================================================
// 2) PRIVACY & SECURITY
// =======================================================
// Credentials are kept in secrets.h and should NOT be committed to GitHub.
#include "secrets.h"

#define DB_ROOT "/devices/aquaSense"

// =======================================================
// System / App Config
// =======================================================
#define LCD_ADDR   0x27
#define LCD_COLS   16
#define LCD_ROWS   2

#define ARGB_COUNT 12
#define ARGB_TYPE  WS2812B
#define ARGB_ORDER GRB

// Timing (non-blocking)
const unsigned long SENSOR_INTERVAL_MS      = 2000;
const unsigned long CONTROL_INTERVAL_MS     = 1000;
const unsigned long LCD_INTERVAL_MS         = 2000;
const unsigned long FIREBASE_PUSH_MS        = 5000;
const unsigned long WIFI_RETRY_MS           = 10000;
const unsigned long FIREBASE_RETRY_MS       = 12000;
const unsigned long BATT_TREND_SAMPLE_MS    = 60000;
const unsigned long NIGHT_BREATH_STEP_MS    = 40;

// Deep sleep
const uint64_t DEEP_SLEEP_5MIN_US = 5ULL * 60ULL * 1000000ULL;

// Battery divider correction (MANDATORY)
const float BATTERY_DIVIDER_RATIO = 4.0f; // ADC_V * 4.0 exactly

// Battery / AC inference thresholds (tune as needed)
const float BATTERY_ONLY_VOLT_THRESHOLD = 11.2f; // inferred battery-only
const uint8_t BATTERY_ONLY_REQUIRED_SAMPLES = 3;

// Thresholds (tune/calibrate)
float TEMP_LOW_C               = 25.0f;
float TEMP_HIGH_C              = 29.0f;
float PH_LOW_LIMIT             = 6.3f;
float PH_HIGH_LIMIT            = 8.3f;
float TURBIDITY_SAFE_NTU       = 35.0f;
float TURBIDITY_CRITICAL_NTU   = 70.0f;
float TDS_SAFE_PPM             = 500.0f;
float TDS_CRITICAL_MAX_PPM     = 1200.0f;

// Filter alert: 2h continuous pump because turbidity not improving
const unsigned long FILTER_ALERT_WINDOW_MS = 2UL * 60UL * 60UL * 1000UL;

// Auto water-change safeguard: max 8 min
const unsigned long WATER_CHANGE_MAX_MS = 8UL * 60UL * 1000UL;
const unsigned long WATER_CHANGE_COOLDOWN_MS = 60UL * 60UL * 1000UL;

// 240V Heater safety watchdog (prevents infinite ON if sensor/element faults)
const unsigned long HEATER_MAX_ON_MS        = 30UL * 60UL * 1000UL; // 30 min hard cut-off
const float         TEMP_SENSOR_MIN_VALID_C = 1.0f;   // below this → sensor open/fault
const float         TEMP_SENSOR_MAX_VALID_C = 40.0f;  // above this → sensor fault / DS18B20 sentinel

// Buzzer pattern
const unsigned long BUZZER_TOGGLE_MS = 400;

// pH placeholder calibration (must calibrate in real system)
float PH_SLOPE  = -5.70f;
float PH_OFFSET = 21.34f;

// =======================================================
// Dummy Data Mode (for uncalibrated sensors / dry-test)
// =======================================================
bool DUMMY_PH         = false;
bool DUMMY_TDS        = false;
bool DUMMY_TURBIDITY  = false;
bool DUMMY_TEMP       = false;
bool DUMMY_BATTERY    = false;

// =======================================================
// Objects
// =======================================================
LiquidCrystal_I2C lcd(LCD_ADDR, LCD_COLS, LCD_ROWS);
RTC_DS3231 rtc;
OneWire oneWire(TEMP_SENSOR_PIN);
DallasTemperature ds18b20(&oneWire);
CRGB leds[ARGB_COUNT];
Servo feederServo;
WebServer server(80);

// Firebase
FirebaseData fbdo;
FirebaseData fbStream;
FirebaseAuth auth;
FirebaseConfig config;

// =======================================================
// Runtime State
// =======================================================
struct SensorState {
  float phValue = 7.0f;
  float phVoltage = 0.0f;
  float tdsPPM = 0.0f;
  float tdsVoltage = 0.0f;
  float turbidityNTU = 0.0f;
  float turbidityVoltage = 0.0f;
  float tempC = 26.0f;
  float battVoltage = 12.0f;
  float battPercent = 80.0f;
};

struct ControlState {
  bool manualMode = false;
  bool manualFan = false;
  bool manualPump = false;
  bool manualHeater = false;
  bool manualBuzzer = false;
  bool feedNow = false;
  bool voiceFeed = false;
  bool voicePump = false;
};

struct OutputState {
  bool fan = false;
  bool pump = false;
  bool heater = false;
  bool buzzer = false;
};

SensorState gS;
ControlState gC;
OutputState gO;

bool wifiConnected = false;
bool firebaseReady = false;
bool filterChangeRequired = false;
bool waterChangeActive = false;
bool chargingInferred = false;
bool batteryOnlyMode = false;

// timers
unsigned long tSensor = 0;
unsigned long tControl = 0;
unsigned long tLCD = 0;
unsigned long tFirebasePush = 0;
unsigned long tWiFiRetry = 0;
unsigned long tFirebaseRetry = 0;
unsigned long tBattTrend = 0;
unsigned long tNightBreath = 0;
unsigned long tBuzzer = 0;

// feeder FSM
enum FeedState { FEED_IDLE, FEED_TO_ANGLE, FEED_HOLD, FEED_RETURN };
FeedState feedState = FEED_IDLE;
unsigned long tFeed = 0;

// filter runtime tracking
unsigned long turbidityPumpStartMs = 0;

// water change tracking
unsigned long waterChangeStartMs = 0;
unsigned long lastWaterChangeStopMs = 0;

// 240V heater watchdog
unsigned long heaterOnStartMs   = 0;
bool          heaterSafetyCutoff = false;

// LCD pages
uint8_t lcdPage = 0;

// night breathing
uint8_t breathV = 20;
int8_t breathDir = 1;

// turbidity SMA + trend
const size_t TURB_SMA_N = 20;
float turbSMAArr[TURB_SMA_N] = {0};
size_t turbSMAIdx = 0;
size_t turbSMACount = 0;
float turbSMA = 0.0f;

const size_t TURB_TREND_N = 12; // 12 points x 1 min ~ 12 min trend
float turbTrendVal[TURB_TREND_N] = {0};
unsigned long turbTrendTime[TURB_TREND_N] = {0};
size_t turbTrendIdx = 0;
size_t turbTrendCount = 0;
float predictedDaysToMaintenance = -1.0f;

// battery trend for charging inference
const size_t BATT_TREND_N = 10;
float battTrend[BATT_TREND_N] = {0};
size_t battTrendIdx = 0;
size_t battTrendCount = 0;
uint8_t batteryOnlySamples = 0;

// =======================================================
// Helpers
// =======================================================
float clampf(float v, float lo, float hi) {
  if (v < lo) return lo;
  if (v > hi) return hi;
  return v;
}

float randf(float a, float b) {
  return a + (float)(esp_random() % 10001) / 10000.0f * (b - a);
}

float adcToVoltage(int raw) {
  return (3.3f * (float)raw) / 4095.0f;
}

String rtcTimestamp() {
  DateTime n = rtc.now();
  char b[25];
  snprintf(b, sizeof(b), "%04d-%02d-%02dT%02d:%02d:%02d",
           n.year(), n.month(), n.day(), n.hour(), n.minute(), n.second());
  return String(b);
}

void allLoadsSafeOff() {
  digitalWrite(FAN_RELAY_PIN, LOW);
  digitalWrite(PUMP_RELAY_PIN, LOW);
  digitalWrite(HEATER_RELAY_PIN, LOW);
  gO.fan = gO.pump = gO.heater = false;
}

void applyOutputs() {
  digitalWrite(FAN_RELAY_PIN,    gO.fan    ? HIGH : LOW);
  digitalWrite(PUMP_RELAY_PIN,   gO.pump   ? HIGH : LOW);
  digitalWrite(HEATER_RELAY_PIN, gO.heater ? HIGH : LOW);
  // NOTE: Buzzer is managed exclusively by the non-blocking 400 ms toggle in loop().
  // Writing BUZZER_PIN here would fight the toggle every 1 s and corrupt the beep pattern.
}

void updateStatusLed() {
  // ON when both Wi-Fi and Firebase are ready, else OFF
  digitalWrite(WIFI_STATUS_LED_PIN, (wifiConnected && firebaseReady) ? HIGH : LOW);
}

// =======================================================
// Sensor Reading
// =======================================================
float readPH() {
  if (DUMMY_PH) {
    gS.phVoltage = 2.5f;
    return randf(6.8f, 7.8f);
  }
  int raw = analogRead(PH_SENSOR_PIN);
  gS.phVoltage = adcToVoltage(raw);
  float ph = PH_OFFSET + PH_SLOPE * gS.phVoltage;
  return clampf(ph, 0.0f, 14.0f);
}

float readTempC() {
  if (DUMMY_TEMP) return randf(24.0f, 30.5f);
  ds18b20.requestTemperatures();
  float t = ds18b20.getTempCByIndex(0);
  // Reject: out-of-range OR DS18B20 power-on sentinel (85.0 °C returned before first valid conversion)
  if (t < -55.0f || t > 125.0f || fabsf(t - 85.0f) < 0.1f) return gS.tempC;
  return t;
}

float readTurbidity() {
  if (DUMMY_TURBIDITY) {
    gS.turbidityVoltage = 2.0f;
    return randf(15.0f, 80.0f);
  }
  int raw = analogRead(TURBIDITY_SENSOR_PIN);
  gS.turbidityVoltage = adcToVoltage(raw);
  float ntu = -1120.4f * gS.turbidityVoltage * gS.turbidityVoltage
            + 5742.3f * gS.turbidityVoltage - 4352.9f;
  if (isnan(ntu) || ntu < 0) ntu = 0;
  return ntu;
}

float readTDS(float tempC) {
  if (DUMMY_TDS) {
    gS.tdsVoltage = 2.1f;
    return randf(250.0f, 1100.0f);
  }
  int raw = analogRead(TDS_SENSOR_PIN);
  gS.tdsVoltage = adcToVoltage(raw);
  float cc = 1.0f + 0.02f * (tempC - 25.0f);
  float cv = gS.tdsVoltage / cc;
  float tds = (133.42f * cv * cv * cv - 255.86f * cv * cv + 857.39f * cv) * 0.5f;
  if (isnan(tds) || tds < 0) tds = 0;
  return tds;
}

float readBatteryV() {
  if (DUMMY_BATTERY) return randf(10.8f, 12.8f);
  int raw = analogRead(BMS_BATTERY_PIN);
  float vAdc = adcToVoltage(raw);
  return vAdc * BATTERY_DIVIDER_RATIO; // exact requirement
}

void updateTurbiditySMA(float x) {
  turbSMAArr[turbSMAIdx] = x;
  turbSMAIdx = (turbSMAIdx + 1) % TURB_SMA_N;
  if (turbSMACount < TURB_SMA_N) turbSMACount++;

  float sum = 0;
  for (size_t i = 0; i < turbSMACount; i++) sum += turbSMAArr[i];
  turbSMA = sum / (float)turbSMACount;
}

void updateTurbidityTrendPrediction(float x) {
  turbTrendVal[turbTrendIdx] = x;
  turbTrendTime[turbTrendIdx] = millis();
  turbTrendIdx = (turbTrendIdx + 1) % TURB_TREND_N;
  if (turbTrendCount < TURB_TREND_N) turbTrendCount++;

  if (turbTrendCount < 4) {
    predictedDaysToMaintenance = -1.0f;
    return;
  }

  size_t oldest = (turbTrendIdx + TURB_TREND_N - turbTrendCount) % TURB_TREND_N;
  size_t newest = (turbTrendIdx + TURB_TREND_N - 1) % TURB_TREND_N;

  float y0 = turbTrendVal[oldest];
  float y1 = turbTrendVal[newest];
  unsigned long dt = turbTrendTime[newest] - turbTrendTime[oldest];
  if (dt == 0) return;

  float slope = (y1 - y0) / (float)dt; // NTU per ms
  if (slope <= 0) {
    predictedDaysToMaintenance = 999.0f; // improving/stable
    return;
  }

  float remain = TURBIDITY_CRITICAL_NTU - y1;
  if (remain <= 0) {
    predictedDaysToMaintenance = 0.0f;
    return;
  }

  float msToCritical = remain / slope;
  predictedDaysToMaintenance = msToCritical / (1000.0f * 60.0f * 60.0f * 24.0f);
  if (predictedDaysToMaintenance > 999.0f) predictedDaysToMaintenance = 999.0f;
}

void updateChargingInference(float battV) {
  battTrend[battTrendIdx] = battV;
  battTrendIdx = (battTrendIdx + 1) % BATT_TREND_N;
  if (battTrendCount < BATT_TREND_N) battTrendCount++;

  if (battTrendCount < 4) return;

  size_t oldest = (battTrendIdx + BATT_TREND_N - battTrendCount) % BATT_TREND_N;
  size_t newest = (battTrendIdx + BATT_TREND_N - 1) % BATT_TREND_N;
  float delta = battTrend[newest] - battTrend[oldest];

  chargingInferred = (delta > 0.05f); // >50mV trend considered charging

  if (battV < BATTERY_ONLY_VOLT_THRESHOLD && !chargingInferred) {
    if (batteryOnlySamples < 255) batteryOnlySamples++;
  } else {
    batteryOnlySamples = 0;
  }
  batteryOnlyMode = (batteryOnlySamples >= BATTERY_ONLY_REQUIRED_SAMPLES);
}

void readAllSensors() {
  gS.tempC = readTempC();
  gS.phValue = readPH();
  gS.turbidityNTU = readTurbidity();
  gS.tdsPPM = readTDS(gS.tempC);
  gS.battVoltage = readBatteryV();

  // Battery % for a 3S Li-ion style pack default range
  gS.battPercent = clampf((gS.battVoltage - 9.0f) * 100.0f / (12.6f - 9.0f), 0.0f, 100.0f);

  updateTurbiditySMA(gS.turbidityNTU);
}

// =======================================================
// ARGB Lighting by RTC (no NTP)
// =======================================================
void setSolidColor(const CRGB &c, uint8_t brightness) {
  FastLED.setBrightness(brightness);
  fill_solid(leds, ARGB_COUNT, c);
  FastLED.show();
}

void setNightBreathing() {
  if (millis() - tNightBreath < NIGHT_BREATH_STEP_MS) return;
  tNightBreath = millis();

  breathV = (uint8_t)((int)breathV + breathDir * 2);
  if (breathV >= 140) breathDir = -1;
  if (breathV <= 15) breathDir = 1;

  FastLED.setBrightness(70);
  for (int i = 0; i < ARGB_COUNT; i++) {
    leds[i] = (i % 2 == 0) ? CHSV(170, 170, breathV) : CHSV(192, 150, breathV);
  }
  FastLED.show();
}

void updateLightingByRTC() {
  DateTime now = rtc.now();
  int h = now.hour();

  if (h >= 6 && h < 10) {
    // Morning sunrise: dim orange/yellow
    setSolidColor(CRGB(255, 145, 40), 90);
  } else if (h >= 10 && h < 18) {
    // Day: bright white/light blue
    setSolidColor(CRGB(180, 225, 255), 180);
  } else {
    // Night: calm breathing blue/purple
    setNightBreathing();
  }
}

// =======================================================
// Feeder Servo FSM
// =======================================================
void requestFeed() {
  if (feedState == FEED_IDLE) gC.feedNow = true;
}

void updateFeeder() {
  switch (feedState) {
    case FEED_IDLE:
      if (gC.feedNow) {
        feederServo.write(95);
        tFeed = millis();
        feedState = FEED_TO_ANGLE;
        gC.feedNow = false;
      }
      break;
    case FEED_TO_ANGLE:
      if (millis() - tFeed >= 600) {
        tFeed = millis();
        feedState = FEED_HOLD;
      }
      break;
    case FEED_HOLD:
      if (millis() - tFeed >= 800) {
        feederServo.write(15);
        tFeed = millis();
        feedState = FEED_RETURN;
      }
      break;
    case FEED_RETURN:
      if (millis() - tFeed >= 500) {
        feedState = FEED_IDLE;
      }
      break;
  }
}

// =======================================================
// Control & Automation
// =======================================================
void startWaterChange() {
  if (waterChangeActive) return;
  if (millis() - lastWaterChangeStopMs < WATER_CHANGE_COOLDOWN_MS) return;
  waterChangeActive = true;
  waterChangeStartMs = millis();
}

void stopWaterChange() {
  waterChangeActive = false;
  lastWaterChangeStopMs = millis();
}

void evaluateFilterAlertLogic() {
  // condition: pump ON due to high turbidity in AUTO mode
  if (!gC.manualMode && gO.pump && gS.turbidityNTU > TURBIDITY_SAFE_NTU) {
    if (turbidityPumpStartMs == 0) {
      turbidityPumpStartMs = millis();
    } else {
      unsigned long runMs = millis() - turbidityPumpStartMs;
      if (runMs >= FILTER_ALERT_WINDOW_MS && gS.turbidityNTU > TURBIDITY_SAFE_NTU) {
        filterChangeRequired = true;
      }
    }
  } else {
    turbidityPumpStartMs = 0;
  }
}
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
void loop() {
  unsigned long now = millis();

  // local dashboard
  server.handleClient();

  // Wi-Fi monitor + retry
  monitorWiFiState();
  if (!wifiConnected && now - tWiFiRetry >= WIFI_RETRY_MS) {
    tWiFiRetry = now;
    tryWiFiConnect();
  }

  // Firebase retry
  if (wifiConnected && !firebaseReady && now - tFirebaseRetry >= FIREBASE_RETRY_MS) {
    tFirebaseRetry = now;
    tryFirebaseStart();
  }

  // sensor cycle
  if (now - tSensor >= SENSOR_INTERVAL_MS) {
    tSensor = now;
    readAllSensors();
  }

  // control/automation cycle
  if (now - tControl >= CONTROL_INTERVAL_MS) {
    tControl = now;
    evaluateAutomation();
  }

  // feeder FSM
  updateFeeder();

  // non-blocking buzzer in normal mode (if ON)
  if (gO.buzzer) {
    if (now - tBuzzer >= BUZZER_TOGGLE_MS) {
      tBuzzer = now;
      digitalWrite(BUZZER_PIN, !digitalRead(BUZZER_PIN));
    }
  } else {
    digitalWrite(BUZZER_PIN, LOW);
  }

  // RTC-based ARGB
  updateLightingByRTC();

  // LCD cycle
  if (now - tLCD >= LCD_INTERVAL_MS) {
    tLCD = now;
    updateLCD();
  }

  // battery trend inference + turbidity trend (every minute)
  if (now - tBattTrend >= BATT_TREND_SAMPLE_MS) {
    tBattTrend = now;
    updateChargingInference(gS.battVoltage);
    updateTurbidityTrendPrediction(gS.turbidityNTU);
  }

  // Firebase push
  if (now - tFirebasePush >= FIREBASE_PUSH_MS) {
    tFirebasePush = now;
    pushFirebase();
  }

  // connection LED
  updateStatusLed();

  // If firebase dropped
  if (firebaseReady && !Firebase.ready()) {
    firebaseReady = false;
  }

  // Deep sleep when inferred battery-only mode
  // requirement: safely turn off high-drain loads and sleep 5 min cycle
  if (batteryOnlyMode) {
    // quick best-effort push before sleep if cloud available
    if (wifiConnected && firebaseReady && Firebase.ready()) {
      pushFirebase();
    }
    enterDeepSleepCycle();
  }
}

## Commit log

2026-08-11 Initial commit - SRAqua Guard source files and documentation
    [Components_List_BOM.csv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]
2026-08-12 feat: enhance licensing, security, and project documentation
    - Implement multi-license model (MIT, CERN-OHL-S-2.0, CC BY 4.0)
    - Secure firmware credentials with secrets.example.h and .gitignore
    - Update README with professional badges, star buttons, and synchronized voice specifications
    - Finalize hardware design, Gerber files, and BOM
    [IoT-Based-Smart-Aquarium-Monitor-&-Control-System-B_Cu.gbr, IoT-Based-Smart-Aquarium-Monitor-&-Control-System-B_Mask.gbr, IoT-Based-Smart-Aquarium-Monitor-&-Co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]
2026-08-12 docs: refine and simplify BOM section in README

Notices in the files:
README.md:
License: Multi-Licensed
